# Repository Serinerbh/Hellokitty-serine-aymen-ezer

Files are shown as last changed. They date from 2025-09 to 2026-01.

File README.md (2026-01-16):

# 🐱 HelloKitty – Projet Robot Chat


### **Les contributeurs :**
-BENJEMAA Aymen
-SOLTANI Ezer
-ROUABAH Serine

## 📚 Table des matières

1. [📜 Présentation générale](#-présentation-générale)
2. [📐 Architecture matérielle](#-architecture-matérielle)
   - [🔌 Schéma système](#-schéma-système)
   - [📌 Pinout STM32](#-pinout-stm32)
   - [🛠️ PCB et design électronique](#-pcb-et-design-électronique)
3. [🧩 Architecture logicielle](#-architecture-logicielle)
   - [🧱 Couches logicielles](#-couches-logicielles)
   - [🕒 Fonctionnement des tâches FreeRTOS](#-fonctionnement-des-tâches-freertos)
   - [🔄 Synchronisation et priorités](#-synchronisation-et-priorités)
4. [⚙️ Drivers et HAL](#-drivers-et-hal)
5. [🎯 Stratégie comportementale](#-stratégie-comportementale)
6. [📊 Tests et validation](#-tests-et-validation)
7. [🔧 Résultats et perspectives](#-résultats-et-perspectives)

## Présentation générale

HelloKitty est un robot mobile autonome conçu pour évoluer sur une surface plane sans bordure, dans un jeu de poursuite entre plusieurs robots. Le projet s’inscrit dans le cadre du module Systèmes Électroniques Avancés de l’ENSEA, et vise à couvrir l’ensemble du cycle de développement embarqué : de la conception du PCB à l’implémentation logicielle temps réel, en passant par la stratégie comportementale.

Le robot est capable de détecter les bords, d’éviter les chutes, de repérer d’autres robots, et de changer de rôle (chat ↔ souris) en fonction des interactions physiques ou visuelles. Le projet met en œuvre des capteurs variés, une architecture logicielle modulaire, et une gestion fine des tâches concurrentes via FreeRTOS.

## **Architecture**  
### **Schéma architectural**  

schema_projet

#  Architecture du système embarqué STM32G431CBU6

Ce projet repose sur un microcontrôleur **STM32G431CBU6**, intégrant divers capteurs, modules de communication, moteurs et interfaces utilisateur pour créer un système autonome capable de capter, traiter et agir dans un environnement physique.

##  Microcontrôleur central
- **STM32G431CBU6** : cœur du système, gère les communications, le traitement des données et le contrôle des périphériques.

## Alimentation
- **Batterie NiMH 7.2V 1.3Ah** : source principale d’énergie.
- **Régulateurs de tension** :
  - **MP1475DJ-LF-P** : convertit la tension en **5V**.
  - **BU33SD5WG-TR** : convertit en **3.3V** pour les composants sensibles.

## Capteurs et modules
- **4 capteurs TOF (Time-of-Flight)** : connectés via **I2C**, pour mesurer les distances.
- **Accéléromètre ADXL343** : connecté en **I2C**, pour détecter les mouvements.
- **Module Bluetooth** : communication sans fil via **UART**.
- **Lidar YDLIDAR X2** : capteur de télémétrie, connecté en **UART**.

## Horloge et programmation
- **Quartz 16MHz** : fournit une horloge stable au microcontrôleur.
- **STLink SWD** : interface de programmation et débogage.
- **Hclk** : 170Mhz.

## Moteurs et contrôle
- **2 pilotes de moteur ZXBM5210** : reçoivent des signaux **PWM** pour contrôler les moteurs gauche et droit.
- **Moteurs avec encodeurs** : permettent un retour de position et de vitesse.

## 🖱️ Interface utilisateur
- **LED** : sortie **GPIO**, pour signalisation.
- **Bouton utilisateur** : entrée **GPIO**, pour interaction manuelle.
- **Bouton reset** : pour redémarrer le système.

## 🔌 Connexions colorées
- **Rouge** : lignes d’alimentation **5V**
- **Orange** : lignes **3.3V**
- **Violet** : **I2C**
- **Bleu** : **UART**
- **Vert** : **GPIO**
- **Noir** : **PWM**

---

Ce schéma illustre l’interconnexion des modules pour un système embarqué intelligent et réactif.

## Fonctionnement interne du robot

Le robot ne se contente pas d’exécuter des actions simples : son microcontrôleur coordonne en continu l’ensemble des capteurs, moteurs et modules pour produire un comportement cohérent et réactif. Cette section décrit la logique interne qui permet au système de fonctionner de manière autonome.

### Organisation logicielle
Le logiciel embarqué est structuré en plusieurs tâches indépendantes.  
Chaque tâche s’occupe d’un domaine précis : analyse des distances, lecture des chocs, gestion des moteurs ou encore surveillance de l’environnement.  
Cette organisation évite qu’une opération bloque les autres et garantit une réactivité constante.

### Système de décision
Le robot suit une hiérarchie de priorités pour réagir correctement aux événements :
- **Sécurité immédiate** : arrêt ou retrait en cas de danger (vide, obstacle trop proche, choc).
- **Évitement** : choix de la direction la plus dégagée grâce aux données du LiDAR.
- **Déplacement normal** : progression ou patrouille lorsque l’environnement est stable.

Cette logique empêche les comportements incohérents et permet des réactions rapides.

### Gestion dynamique des moteurs
Les moteurs sont ajustés en permanence selon la situation :
- correction de trajectoire,
- adaptation de la vitesse,
- compensation en cas de résistance ou de choc.

Le microcontrôleur calcule ces ajustements en temps réel, tandis que les drivers appliquent les consignes via PWM.

### Fusion des capteurs
Les informations issues des différents capteurs sont combinées pour obtenir une vision plus fiable de l’environnement :
- les ToF surveillent les bords,
- le LiDAR analyse l’espace autour du robot,
- l’accéléromètre détecte les impacts ou blocages.

Cette fusion permet d’anticiper les risques et d’adapter le comportement du robot de manière fluide.

### États internes
Le robot fonctionne comme une machine à états, chacun correspondant à un comportement précis :
- exploration,
- évitement,
- collision détectée,
- danger de chute,
- blocage,
- repos.

Chaque état définit les actions à effectuer et les conditions pour passer à un autre état.

### Indicateurs lumineux
Les LEDs servent de retour visuel pour comprendre l’état du robot :
- clignotement rapide : alerte,
- clignotement lent : attente,
- lumière fixe : fonctionnement normal.

Elles permettent de diagnostiquer rapidement le comportement du robot sans accéder au code.

### Synchronisation des communications
Les différents protocoles (UART, SPI, I2C) fonctionnent en parallèle.  
Pour éviter les conflits, les échanges sont cadencés et certaines lectures sont prioritaires.  
Les interruptions matérielles assurent la prise en charge immédiate des événements critiques.

---

Cette architecture logicielle permet au robot d’être autonome, réactif et capable de s’adapter en temps réel à son environnement.

##  Partie Hardware

Cette section décrit l’architecture matérielle du robot, ses composants électroniques, et les schémas associés.


### 🔌 Schéma global du système
Le système repose sur un microcontrôleur **STM32G431CBU6** qui coordonne les capteurs, les moteurs, les régulateurs et les interfaces utilisateur.

---

### ⚙️ Microcontrôleur et interfaces
Le microcontrôleur est au cœur du système. Il est connecté :
- aux moteurs via des signaux **PWM** et des entrées d’encodeurs,
- aux capteurs via **UART**, **I2C**, et **GPIO**,
- à un **STLink/SWD** pour la programmation et le débogage.



---

### 🔋 Alimentation et régulation
Le robot est alimenté par une batterie **NiMH 7.2V**, régulée en deux tensions :
- **5V** via le régulateur **MP1475DJ-LF-P**,
- **3.3V** via le régulateur **BU33SD5WG-TR**.

Ces tensions alimentent les moteurs, le microcontrôleur et les capteurs sensibles.



---

### 🦾 Pilotes de moteurs
Chaque moteur est contrôlé par un circuit **ZXBM5210-SP**, avec :
- deux entrées **PWM** pour la vitesse et la direction,
- deux sorties vers le moteur (Motor+ / Motor−),
- des entrées d’encodeurs pour le retour de position.

Chaque moteur dispose de son propre driver et de ses propres signaux.



---

### 📡 Capteurs
Le système intègre :
- **4 capteurs TOF** pour la détection de bordure,
- **1 accéléromètre ADXL343** pour les chocs et mouvements,
- **1 LiDAR YDLIDAR X2** pour la cartographie et l’évitement,
- **1 module Bluetooth** pour la communication sans fil.

Tous ces capteurs sont connectés au microcontrôleur via **I2C**, **SPI**, **UART** ou **GPIO**.


---

### 🖱️ Interface utilisateur
Le robot dispose :
- de **LEDs** pour indiquer son état (obstacle, marche, pause…),
- d’un **bouton utilisateur** pour les interactions manuelles,
- d’un **bouton reset** pour redémarrer le système.
##im

---

### 🧩 Organisation des fichiers KiCad
Les schémas sont répartis en plusieurs fichiers :
- `pucontrolleur.kicad.sch` : microcontrôleur et interfaces
- `moteur1.kicad.sch` / `moteur2.kicad.sch` : circuits moteurs
- `regulateurs.kicad.sch` : alimentation
- `capteurs.kicad.sch` : capteurs et communication

---

Cette architecture matérielle permet au robot d’être autonome, réactif et modulaire. Chaque composant est interconnecté pour assurer un fonctionnement fluide et sécurisé.

https://github.com/user-attachments/assets/3a07851f-27b0-4f3c-a773-fe1d66b704f5

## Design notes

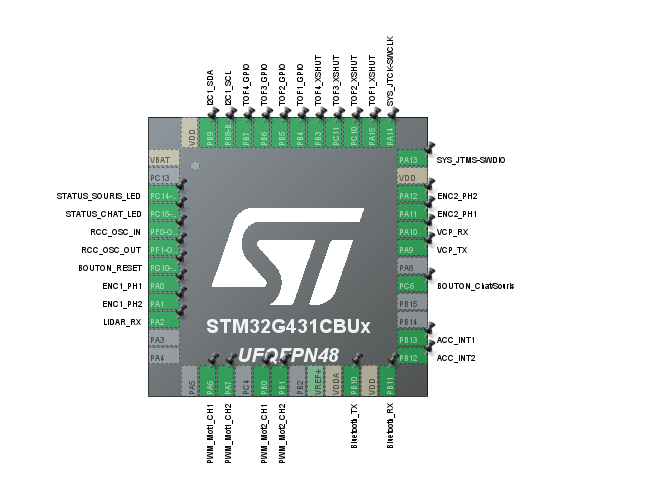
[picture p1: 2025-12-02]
Pinout.png

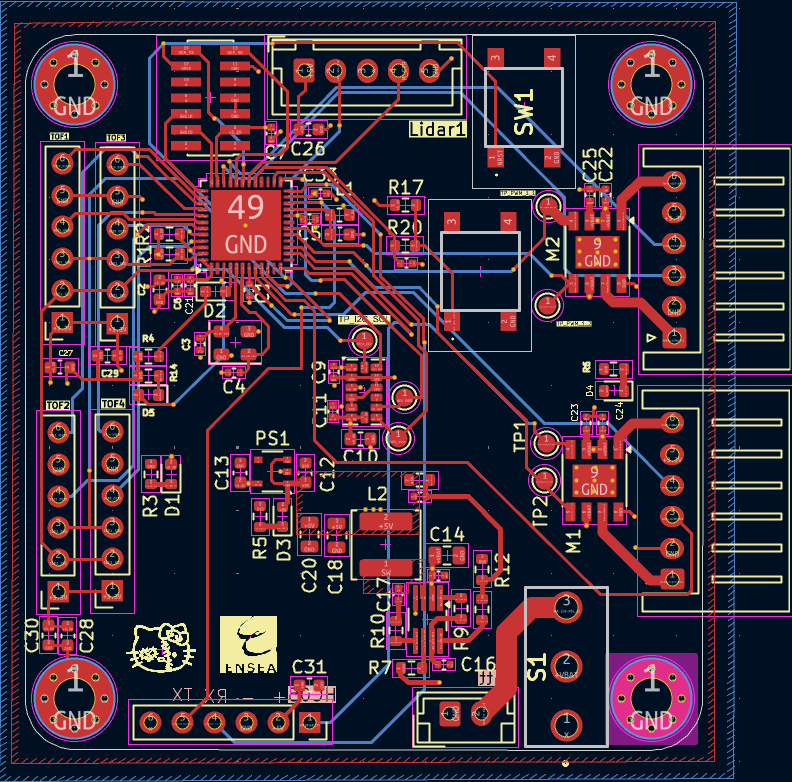
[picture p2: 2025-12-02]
schema.png

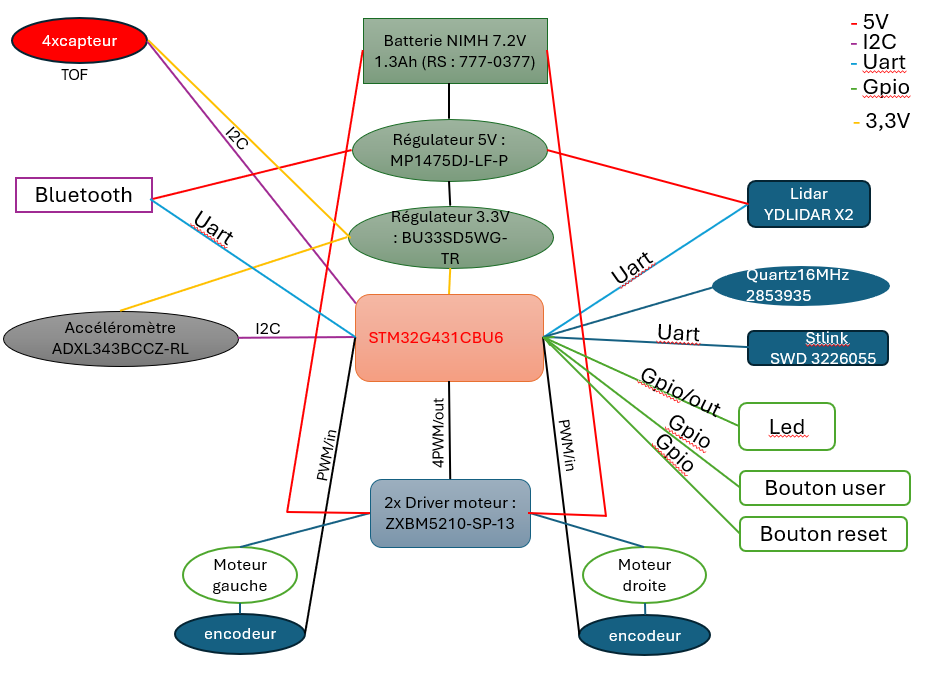
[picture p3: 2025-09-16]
schema_projet.png

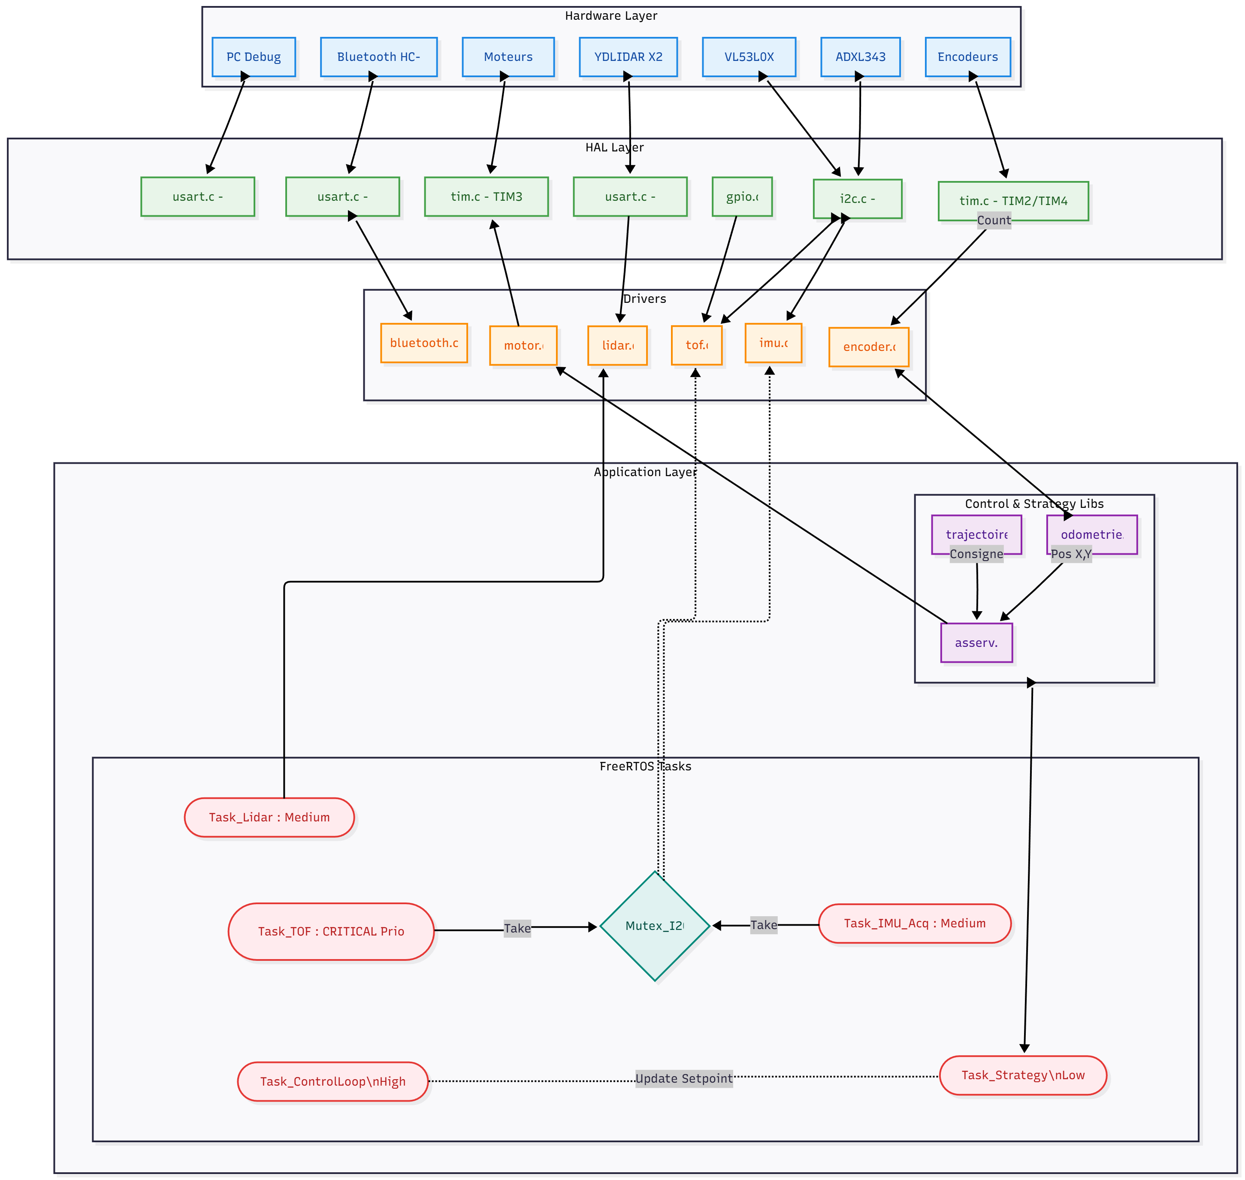
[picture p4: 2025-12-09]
diagram.png

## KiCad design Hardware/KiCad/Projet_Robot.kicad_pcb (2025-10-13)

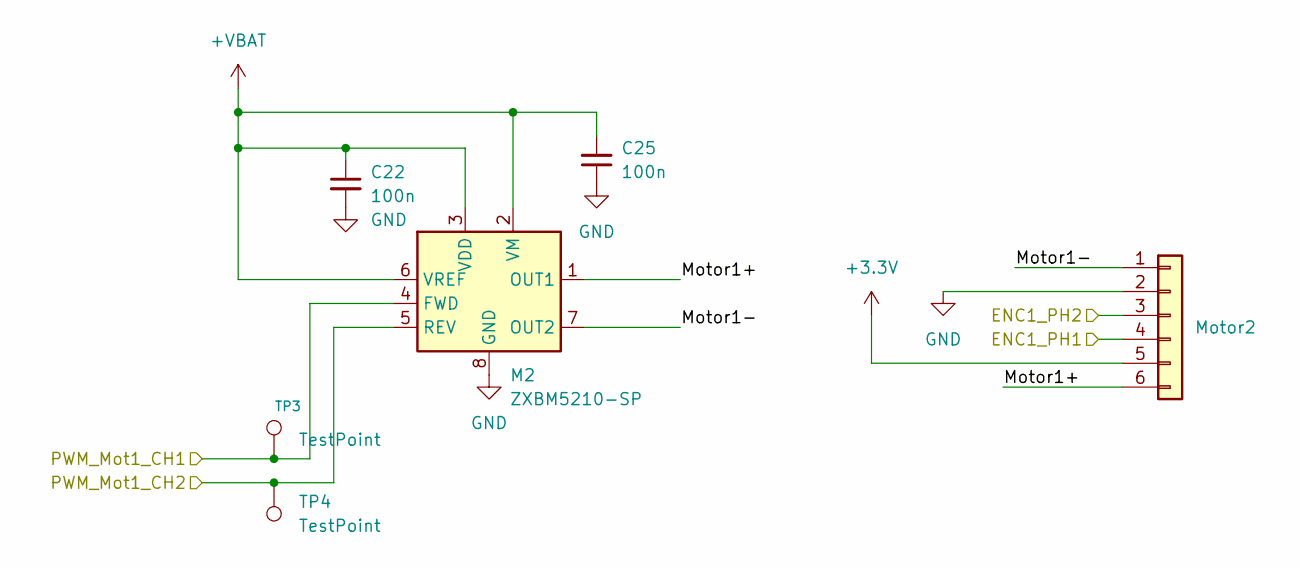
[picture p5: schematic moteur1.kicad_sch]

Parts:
C22, C25: 100n; C_0402_1005Metric
M2: ZXBM5210-SP; Diodes_SO-8EP
Motor2: Conn_01x06; JST_XH_S6B-XH-A_1x06_P2.50mm_Horizontal
TP3, TP4: TestPoint; TestPoint_Pad_D1.5mm

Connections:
+3.3V: Motor2.5; also elsewhere on the board
+VBAT: C22.1, C25.2, M2.2 (VM), M2.3 (VDD), M2.6 (VREF); also elsewhere on the board
/Moteur2/ENC1_PH1: Motor2.4; also elsewhere on the board
/Moteur2/ENC1_PH2: Motor2.3; also elsewhere on the board
/Moteur2/Motor1+: M2.1 (OUT1), Motor2.6
/Moteur2/Motor1-: M2.7 (OUT2), Motor2.1
/Moteur2/PWM_Mot1_CH1: M2.4 (FWD), TP3.1; also elsewhere on the board
GND: C22.2, C25.1, M2.8 (GND), M2.9 (GND), Motor2.2; also elsewhere on the board

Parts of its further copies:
C23, C24: 100n; C_0402_1005Metric
M1: ZXBM5210-SP; Diodes_SO-8EP
Motor1: Conn_01x06; JST_XH_S6B-XH-A_1x06_P2.50mm_Horizontal
TP1, TP2: TestPoint; TestPoint_Pad_D1.5mm

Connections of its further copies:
+3.3V: Motor1.5; also elsewhere on the board
+VBAT: C23.1, C24.2, M1.2 (VM), M1.3 (VDD), M1.6 (VREF); also elsewhere on the board
/Moteur1/ENC1_PH1: Motor1.4; also elsewhere on the board
/Moteur1/ENC1_PH2: Motor1.3; also elsewhere on the board
/Moteur1/Motor1+: M1.1 (OUT1), Motor1.6
/Moteur1/Motor1-: M1.7 (OUT2), Motor1.1
/Moteur1/PWM_Mot1_CH1: M1.4 (FWD), TP1.1; also elsewhere on the board
GND: C23.2, C24.1, M1.8 (GND), M1.9 (GND), Motor1.2; also elsewhere on the board

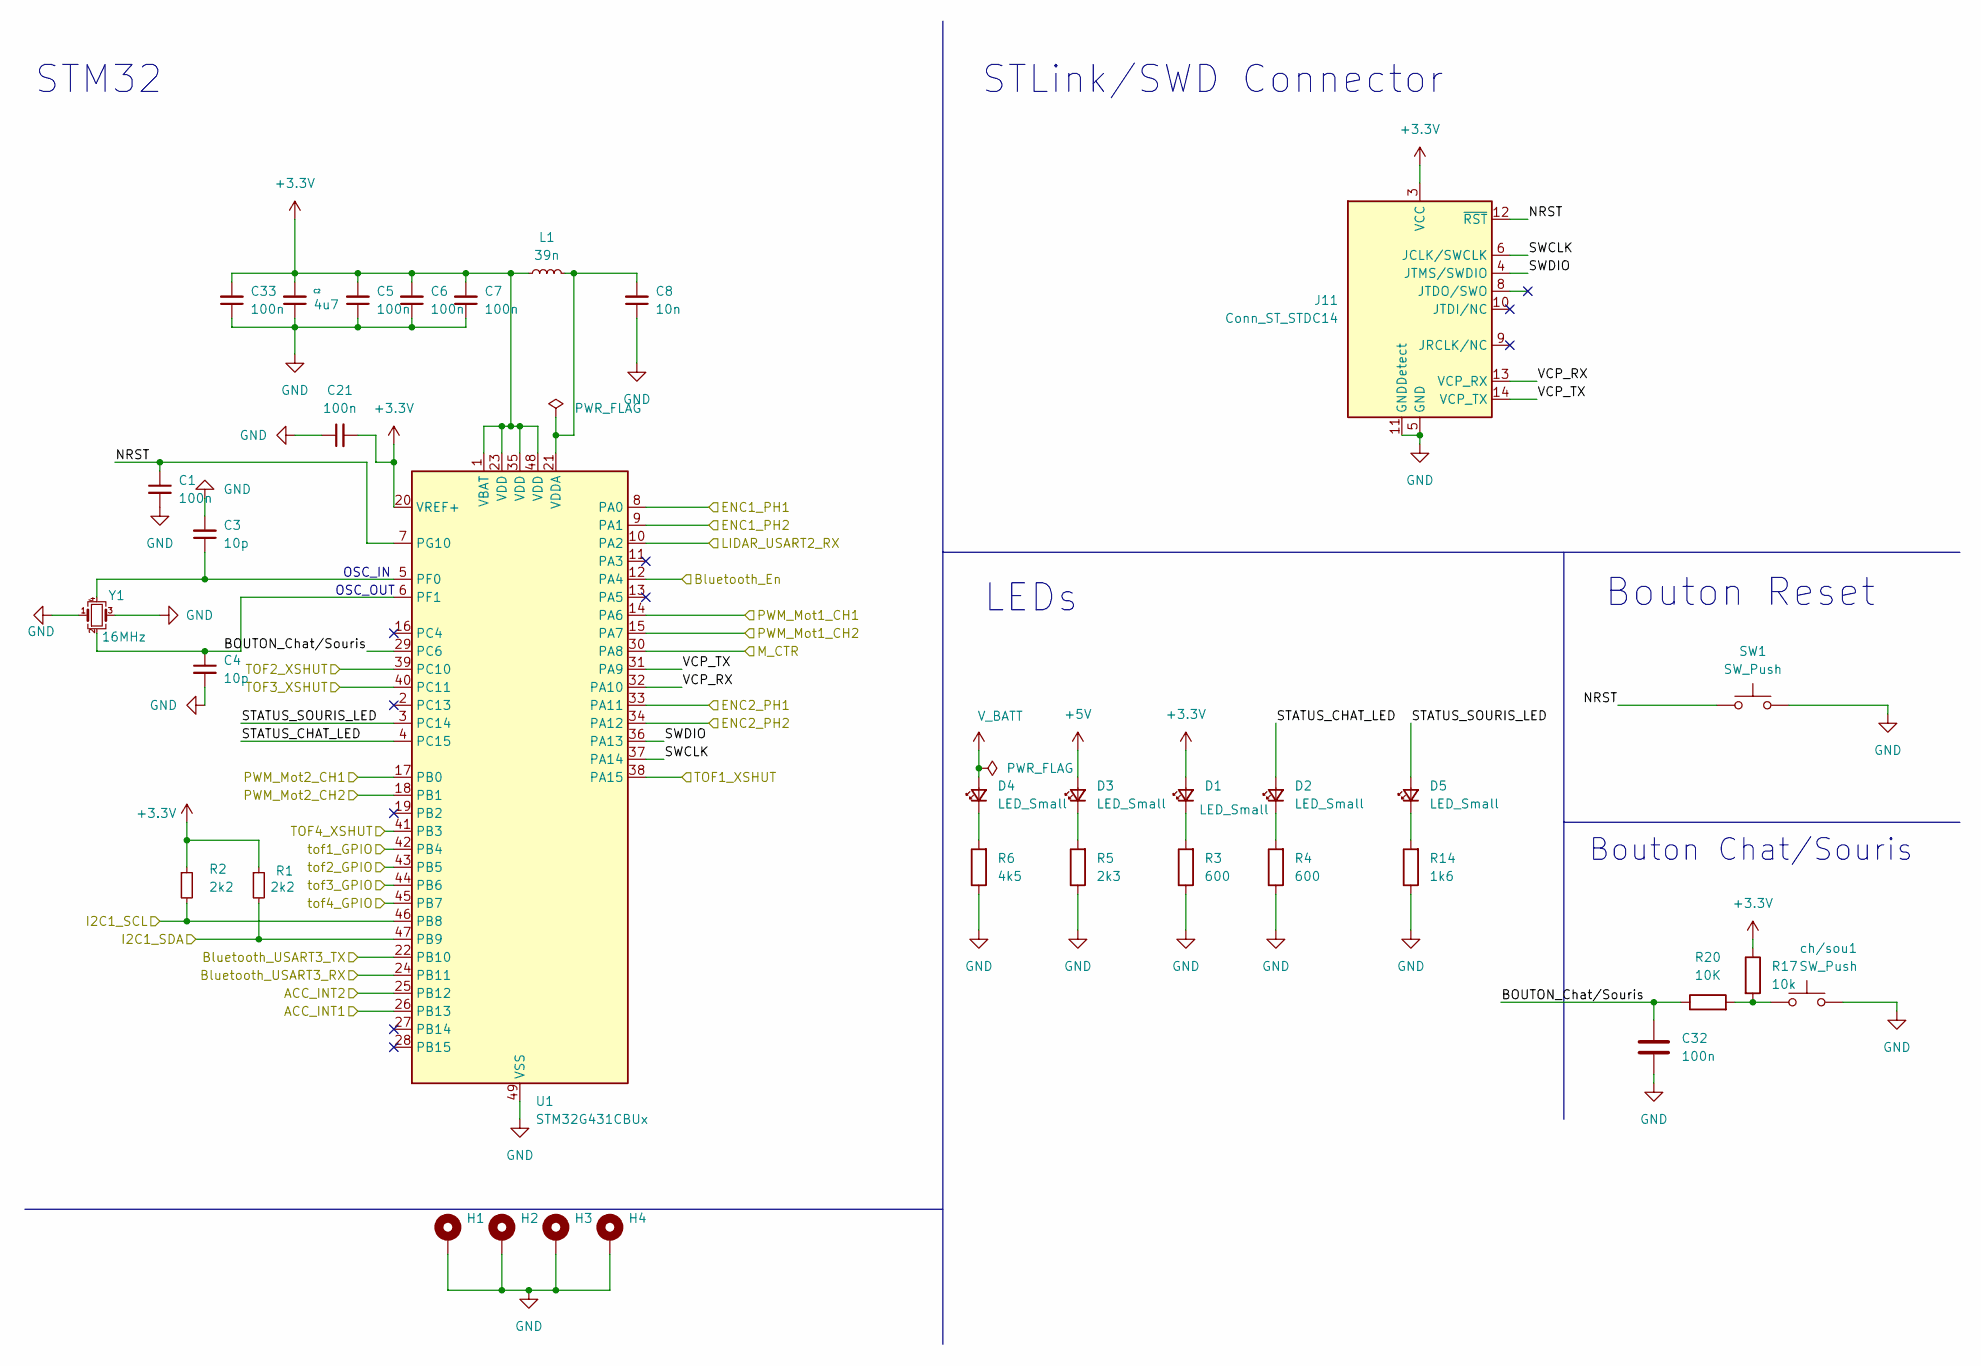
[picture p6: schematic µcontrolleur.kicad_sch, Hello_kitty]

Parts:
C1, C5, C6, C7, C21, C32, C33: 100n; C_0402_1005Metric
C2: 4u7; C_0603_1608Metric
C3, C4: 10p; C_0402_1005Metric
C8: 10n; C_0603_1608Metric
D1, D2, D3, D4, D5: LED_Small; LED_0603_1608Metric
H1, H2, H3, H4: MountingHole_Pad; MountingHole_3.2mm_M3_Pad_Via
J11: Conn_ST_STDC14; PinHeader_2x07_P1.27mm_Vertical_SMD
L1: 39n; L_0603_1608Metric
R1, R2: 2k2; R_0603_1608Metric
R3, R4: 600; R_0603_1608Metric
R5: 2k3; R_0603_1608Metric
R6: 4k5; R_0603_1608Metric
R14: 1k6; R_0603_1608Metric
R17: 10k; R_0603_1608Metric
R20: 10K; R_0603_1608Metric
SW1: SW_Push; SW Push 1P1T NO 6x6mm H9.5mm
U1: STM32G431CBUx; QFN-48-1EP_7x7mm_P0.5mm_EP5.6x5.6mm
Y1: 16MHz; Crystal_SMD_EuroQuartz_MT-4Pin_3.2x2.5mm
ch/sou1: SW_Push; SW Push 1P1T NO 6x6mm H9.5mm

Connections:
+3.3V: C2.2, C5.2, C6.2, C7.2, C21.2, C33.2, D1.2 (A), J11.3 (VCC), L1.1, R1.1, R2.1, R17.1, U1.1 (VBAT), U1.20 (VREF+), U1.23 (VDD), U1.35 (VDD), U1.48 (VDD); also elsewhere on the board
+5V: D3.2 (A); also elsewhere on the board
/Capteurs/ACC_INT1: U1.26 (PB13); also elsewhere on the board
/Capteurs/ACC_INT2: U1.25 (PB12); also elsewhere on the board
/Capteurs/Bluetooth_En: U1.12 (PA4); also elsewhere on the board
/Capteurs/Bluetooth_USART3_RX: U1.24 (PB11); also elsewhere on the board
/Capteurs/Bluetooth_USART3_TX: U1.22 (PB10); also elsewhere on the board
/Capteurs/I2C1_SCL: R2.2, U1.46 (PB8); also elsewhere on the board
/Capteurs/I2C1_SDA: R1.2, U1.47 (PB9); also elsewhere on the board
/Capteurs/LIDAR_USART2_RX: U1.10 (PA2); also elsewhere on the board
/Capteurs/M_CTR: U1.30 (PA8); also elsewhere on the board
/Capteurs/TOF1_XSHUT: U1.38 (PA15); also elsewhere on the board
/Capteurs/TOF2_XSHUT: U1.39 (PC10); also elsewhere on the board
/Capteurs/TOF3_XSHUT: U1.40 (PC11); also elsewhere on the board
/Capteurs/TOF4_XSHUT: U1.41 (PB3); also elsewhere on the board
/Capteurs/tof1_GPIO: U1.42 (PB4); also elsewhere on the board
/Capteurs/tof2_GPIO: U1.43 (PB5); also elsewhere on the board
/Capteurs/tof3_GPIO: U1.44 (PB6); also elsewhere on the board
/Capteurs/tof4_GPIO: U1.45 (PB7); also elsewhere on the board
/Moteur1/ENC1_PH1: U1.8 (PA0); also elsewhere on the board
/Moteur1/ENC1_PH2: U1.9 (PA1); also elsewhere on the board
/Moteur1/PWM_Mot1_CH1: U1.14 (PA6); also elsewhere on the board
/Moteur2/ENC1_PH1: U1.33 (PA11); also elsewhere on the board
/Moteur2/ENC1_PH2: U1.34 (PA12); also elsewhere on the board
/Moteur2/PWM_Mot1_CH1: U1.17 (PB0); also elsewhere on the board
/µcontrolleur/BOUTON_Chat/Souris: C32.1, R20.1, U1.29 (PC6)
/µcontrolleur/NRST: C1.1, J11.12 (~RST), SW1.1, U1.7 (PG10)
/µcontrolleur/STATUS_CHAT_LED: D2.2 (A), U1.4 (PC15)
/µcontrolleur/STATUS_SOURIS_LED: D5.2 (A), U1.3 (PC14)
/µcontrolleur/SWCLK: J11.6 (JCLK/SWCLK), U1.37 (PA14)
/µcontrolleur/SWDIO: J11.4 (JTMS/SWDIO), U1.36 (PA13)
/µcontrolleur/VCP_RX: J11.13 (VCP_RX), U1.32 (PA10)
/µcontrolleur/VCP_TX: J11.14 (VCP_TX), U1.31 (PA9)
GND: C1.2, C2.1, C3.2, C4.2, C5.1, C6.1, C7.1, C8.1, C21.1, C32.2, C33.1, H1.1, H2.1, H3.1, H4.1, J11.5 (GND), J11.7 (GND), J11.11 (GNDDetect), R3.1, R4.1, R5.1, R6.1, R14.1, SW1.2, U1.49 (VSS), Y1.1, Y1.3, ch/sou1.2; also elsewhere on the board
unnamed: D1.1 (K), R3.2
unnamed: D2.1 (K), R4.2
unnamed: D3.1 (K), R5.2
unnamed: D4.1 (K), R6.2
unnamed: D5.1 (K), R14.2
unnamed: R17.2, R20.2, ch/sou1.1
unnamed: C3.1, U1.5 (PF0), Y1.4
unnamed: C4.1, U1.6 (PF1), Y1.2
unnamed: C8.2, L1.2, U1.21 (VDDA)
V_BATT: D4.2 (A)

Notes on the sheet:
OSC_OUT
STM32
LEDs
STLink/SWD Connector
Bouton Chat/Souris
Bouton Reset
OSC_IN

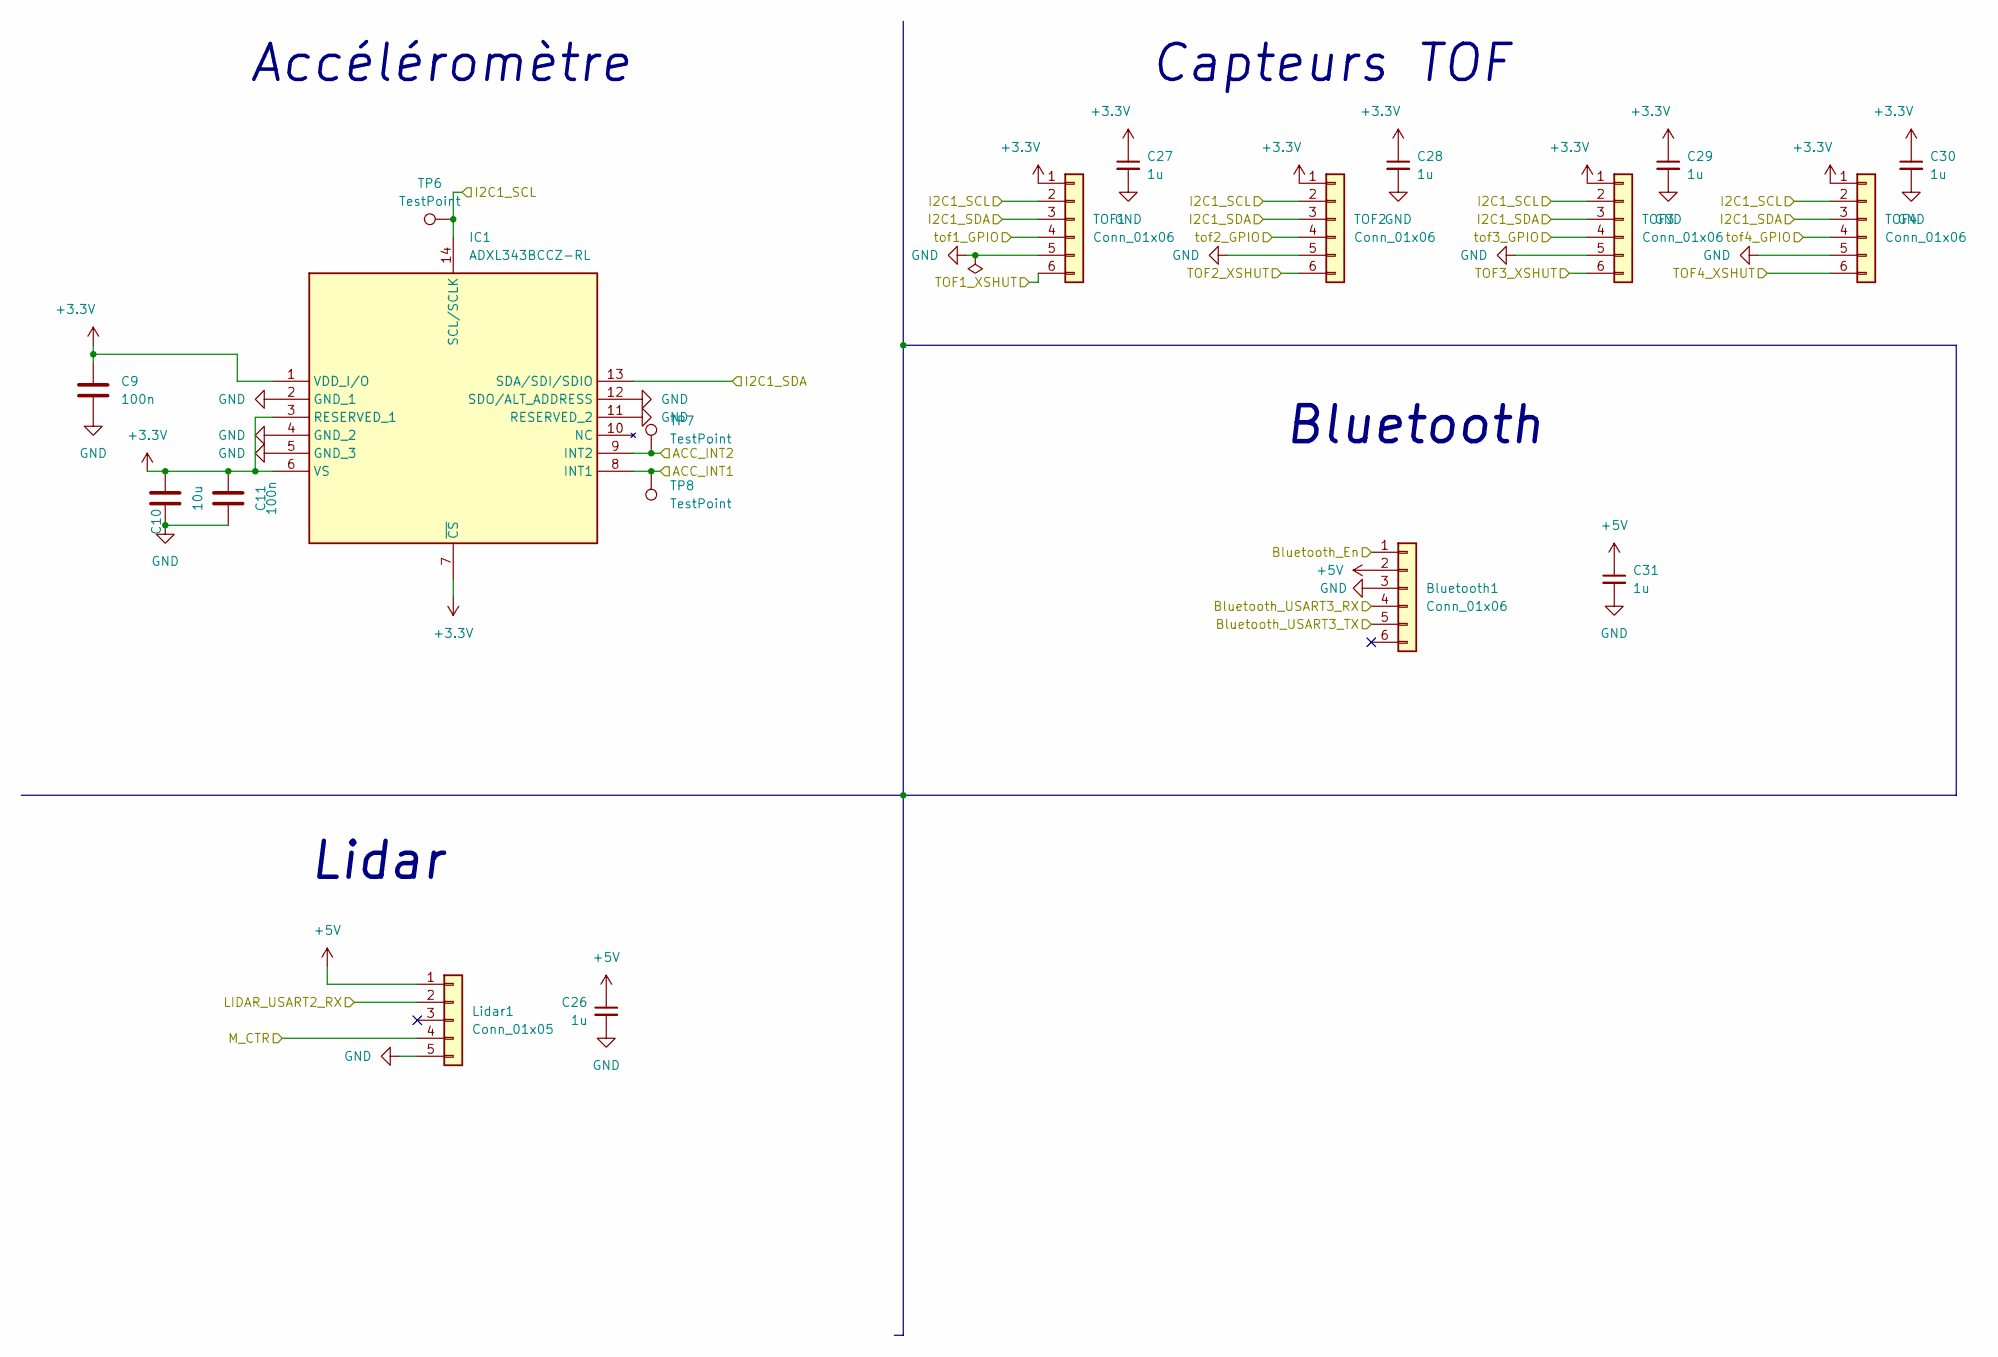
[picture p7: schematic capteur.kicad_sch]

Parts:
Bluetooth1: Conn_01x06; PinSocket_1x06_P2.54mm_Vertical
C9, C11: 100n; C_0402_1005Metric
C10: 10u; C_0603_1608Metric
C26, C27, C28, C29, C30, C31: 1u; C_0603_1608Metric
IC1: ADXL343BCCZ-RL; LGA-14_3x5mm_P0.8mm_LayoutBorder1x6y; Mouser Part Number 584-ADXL343BCCZ-R
Lidar1: Conn_01x05; JST_XH_B5B-XH-A_1x05_P2.50mm_Vertical
TOF1, TOF2, TOF3, TOF4: Conn_01x06; PinSocket_1x06_P2.54mm_Vertical
TP6, TP7, TP8: TestPoint; TestPoint_Pad_D1.5mm

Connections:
+3.3V: C9.2, C10.2, C11.2, C27.1, C28.1, C29.1, C30.1, IC1.1 (VDD_I/O), IC1.3 (RESERVED_1), IC1.6 (VS), IC1.7 (~CS), TOF1.1, TOF2.1, TOF3.1, TOF4.1; also elsewhere on the board
+5V: Bluetooth1.2, C26.1, C31.1, Lidar1.1; also elsewhere on the board
/Capteurs/ACC_INT1: IC1.8 (INT1), TP8.1; also elsewhere on the board
/Capteurs/ACC_INT2: IC1.9 (INT2), TP7.1; also elsewhere on the board
/Capteurs/Bluetooth_En: Bluetooth1.1; also elsewhere on the board
/Capteurs/Bluetooth_USART3_RX: Bluetooth1.4; also elsewhere on the board
/Capteurs/Bluetooth_USART3_TX: Bluetooth1.5; also elsewhere on the board
/Capteurs/I2C1_SCL: IC1.14 (SCL/SCLK), TOF1.2, TOF2.2, TOF3.2, TOF4.2, TP6.1; also elsewhere on the board
/Capteurs/I2C1_SDA: IC1.13 (SDA/SDI/SDIO), TOF1.3, TOF2.3, TOF3.3, TOF4.3; also elsewhere on the board
/Capteurs/LIDAR_USART2_RX: Lidar1.2; also elsewhere on the board
/Capteurs/M_CTR: Lidar1.4; also elsewhere on the board
/Capteurs/TOF1_XSHUT: TOF1.6; also elsewhere on the board
/Capteurs/TOF2_XSHUT: TOF2.6; also elsewhere on the board
/Capteurs/TOF3_XSHUT: TOF3.6; also elsewhere on the board
/Capteurs/TOF4_XSHUT: TOF4.6; also elsewhere on the board
/Capteurs/tof1_GPIO: TOF1.4; also elsewhere on the board
/Capteurs/tof2_GPIO: TOF2.4; also elsewhere on the board
/Capteurs/tof3_GPIO: TOF3.4; also elsewhere on the board
/Capteurs/tof4_GPIO: TOF4.4; also elsewhere on the board
GND: Bluetooth1.3, C9.1, C10.1, C11.1, C26.2, C27.2, C28.2, C29.2, C30.2, C31.2, IC1.2 (GND_1), IC1.4 (GND_2), IC1.5 (GND_3), IC1.11 (RESERVED_2), IC1.12 (SDO/ALT_ADDRESS), Lidar1.5, TOF1.5, TOF2.5, TOF3.5, TOF4.5; also elsewhere on the board

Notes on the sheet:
Lidar
Bluetooth
Accéléromètre
Capteurs TOF

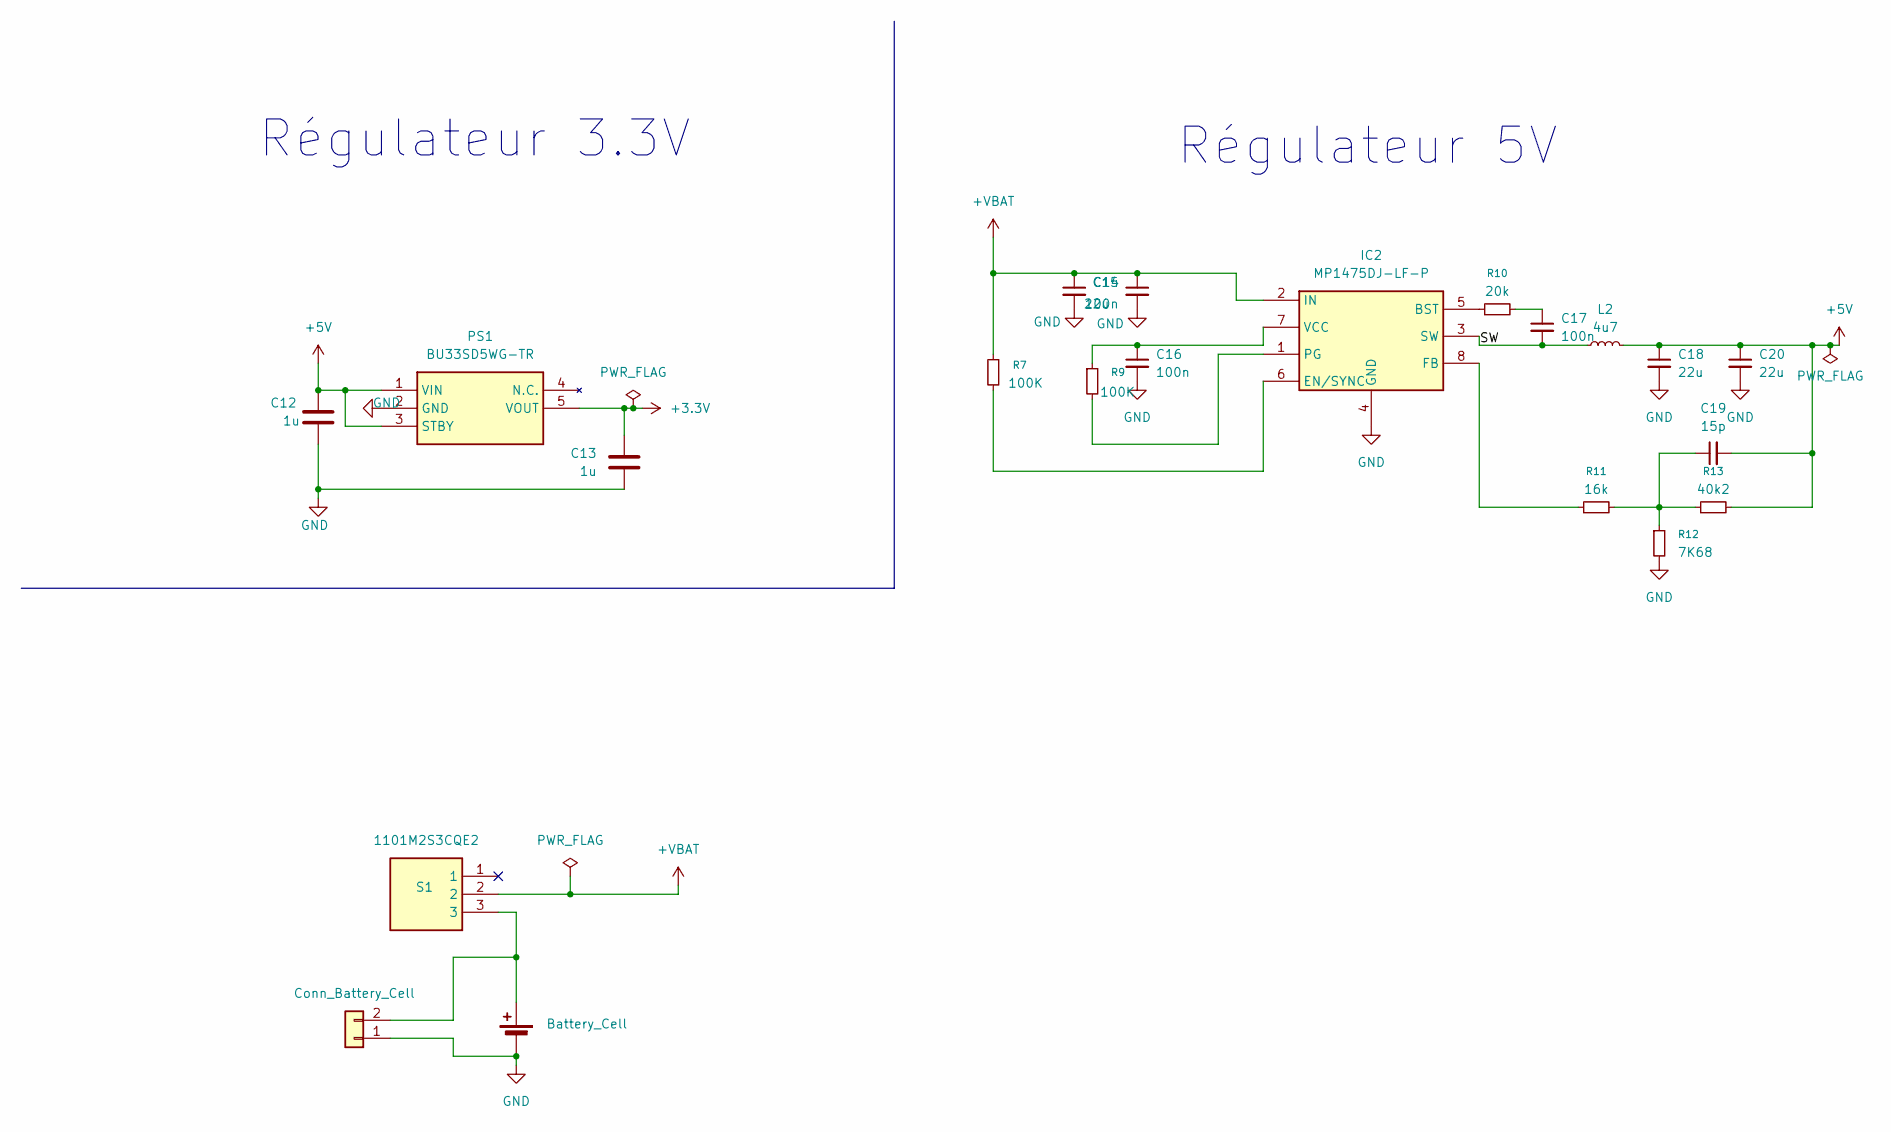
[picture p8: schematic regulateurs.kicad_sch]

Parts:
BT1: Battery_Cell; JST_XH_S2B-XH-A-1_1x02_P2.50mm_Horizontal
C12, C13: 1u; C_0603_1608Metric
C14, C18, C20: 22u; C_0805_2012Metric
C15, C16, C17: 100n; C_0402_1005Metric
C19: 15p; C_0402_1005Metric
IC2: MP1475DJ-LF-P; TSOT-23-8_HandSoldering; Manufacturer_Part_Number MP1475DJ-LF-P
J1: Conn_Battery_Cell; JST_EH_B2B-EH-A_1x02_P2.50mm_Vertical
L2: 4u7; L_APV_ANR5040
PS1: BU33SD5WG-TR; TSOP-5_1.65x3.05mm_P0.95mm; Manufacturer_Part_Number BU33SD5WG-TR; Mouser Part Number 755-BU33SD5WG-TR
R7, R9: 100K; R_0603_1608Metric
R10: 20k; R_0603_1608Metric
R11: 16k; R_0603_1608Metric
R12: 7K68; R_0603_1608Metric
R13: 40k2; R_0603_1608Metric
S1: 1101M2S3CQE2; 1101M2S3QE2; Manufacturer_Part_Number 1101M2S3CQE2

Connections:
+3.3V: C13.2, PS1.5 (VOUT); also elsewhere on the board
+5V: C12.1, C18.1, C19.2, C20.1, L2.2, PS1.1 (VIN), PS1.3 (STBY), R13.2; also elsewhere on the board
+VBAT: C14.1, C15.1, IC2.2 (IN), R7.1, S1.2; also elsewhere on the board
/Régulateurs/SW: C17.2, IC2.3 (SW), L2.1
GND: C12.2, C13.1, C14.2, C15.2, C16.2, C18.2, C20.2, IC2.4 (GND), J1.1, PS1.2 (GND), R12.2; also elsewhere on the board
unnamed: C17.1, R10.2
unnamed: C19.1, R11.2, R12.1, R13.1
unnamed: IC2.5 (BST), R10.1
unnamed: IC2.6 (EN/SYNC), R7.2
unnamed: IC2.8 (FB), R11.1
unnamed: IC2.1 (PG), R9.2
unnamed: C16.1, IC2.7 (VCC), R9.1
unnamed: BT1.1 (+), J1.2, S1.3

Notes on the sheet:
Régulateur 5V
Régulateur 3.3V

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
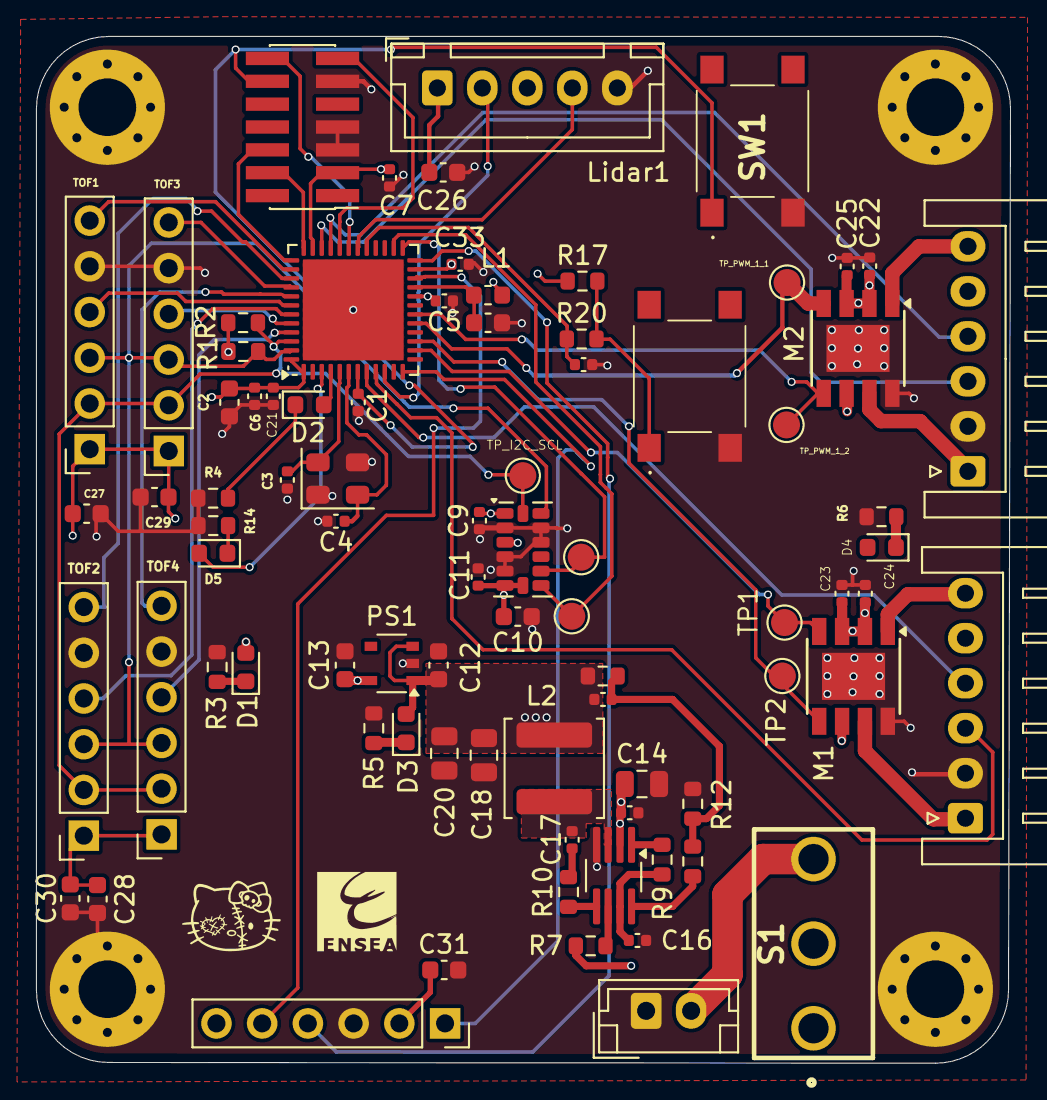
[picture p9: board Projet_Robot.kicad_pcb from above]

Board: 4 copper layers, 54.1 x 57.0 mm, 87 parts (0 on the bottom side), 59 nets.

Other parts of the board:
HelloKitty: L; logo hello
TP_PWM_1_2: TestPoint; TestPoint_Pad_D1.5mm

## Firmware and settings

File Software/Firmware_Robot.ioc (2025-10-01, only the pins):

Mcu.UserName=STM32G431CBUx
PA0.GPIO_Label=ENC1_PH1
PA0.Signal=S_TIM2_CH1
PA1.GPIO_Label=ENC1_PH2
PA1.Signal=S_TIM2_CH2
PA10.GPIO_Label=VCP_RX
PA10.Signal=USART1_RX
PA11.GPIO_Label=ENC2_PH1
PA11.Signal=S_TIM4_CH1
PA12.GPIO_Label=ENC2_PH2
PA12.Signal=S_TIM4_CH2
PA13.Signal=SYS_JTMS-SWDIO
PA14.Signal=SYS_JTCK-SWCLK
PA15.GPIO_Label=TOF1_XSHUT
PA15.Signal=GPIO_Output
PA2.GPIO_Label=LIDAR_RX
PA2.Signal=USART2_TX
PA6.GPIO_Label=PWM_Mot1_CH1
PA6.Signal=S_TIM3_CH1
PA7.GPIO_Label=PWM_Mot1_CH2
PA7.Signal=S_TIM3_CH2
PA9.GPIO_Label=VCP_TX
PA9.Signal=USART1_TX
PB0.GPIO_Label=PWM_Mot2_CH1
PB0.Signal=S_TIM3_CH3
PB1.GPIO_Label=PWM_Mot2_CH2
PB1.Signal=S_TIM3_CH4
PB10.GPIO_Label=Bluetooth_TX
PB10.Signal=USART3_TX
PB11.GPIO_Label=Bluetooth_RX
PB11.Signal=USART3_RX
PB12.GPIO_Label=ACC_INT2
PB12.Signal=GPIO_Input
PB13.GPIO_Label=ACC_INT1
PB13.Signal=GPIO_Input
PB3.GPIO_Label=TOF4_XSHUT
PB3.Signal=GPIO_Output
PB4.GPIO_Label=TOF1_GPIO
PB4.Signal=GPIO_Output
PB5.GPIO_Label=TOF2_GPIO
PB5.Signal=GPIO_Output
PB6.GPIO_Label=TOF3_GPIO
PB6.Signal=GPIO_Output
PB7.GPIO_Label=TOF4_GPIO
PB7.Signal=GPIO_Output
PB8-BOOT0.Signal=I2C1_SCL
PB9.Signal=I2C1_SDA
PC10.GPIO_Label=TOF2_XSHUT
PC10.Signal=GPIO_Output
PC11.GPIO_Label=TOF3_XSHUT
PC11.Signal=GPIO_Output
PC14-OSC32_IN.GPIO_Label=STATUS_SOURIS_LED
PC14-OSC32_IN.Signal=GPIO_Output
PC15-OSC32_OUT.GPIO_Label=STATUS_CHAT_LED
PC15-OSC32_OUT.Signal=GPIO_Output
PC6.GPIO_Label=BOUTON_Chat/Souris
PC6.Signal=GPIO_Input
PF0-OSC_IN.Signal=RCC_OSC_IN
PF1-OSC_OUT.Signal=RCC_OSC_OUT
PG10-NRST.GPIO_Label=BOUTON_RESET
PG10-NRST.Signal=GPIO_Input

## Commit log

2025-09-24 review pcb
    [Projet_Robot.kicad_pcb, Projet_Robot.kicad_sch, capteur.kicad_sch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]
2025-09-24 1
    u
    [moteur1.kicad_sch]
2025-09-30 s
    s
    [Projet_Robot.kicad_pcb, capteur.kicad_sch, regulateurs.kicad_sch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]
2025-10-13 check LF
    [Projet_Robot.kicad_pcb, capteur.kicad_sch, moteur1.kicad_sch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]
2025-11-18 test motor
2025-12-02 Ajout des tests unitaires : accéléromètre et LIDAR
2025-12-03 code Drivers HC_05
2025-12-09 Driver Lidar & Accelerometre
2025-12-09 Update driver Lidar & IMU
2025-12-10 intégration des tâches FreeRTOS : Lidar & Accélerometre
2025-12-13 Intégration FreeRTOS avec drivers Lidar, IMU, TOF et moteurs
2026-01-01 asservissement PID, sécurité TOF par interruption et filtrage LIDAR
2026-01-09 Implémentation architecture FreeRTOS (Control, Safety, Lidar, IMU)
2026-01-09 implémentation de la stratégie, du suivi de cible et du contrôle Bluetooth
    - Ajout de la machine à états (RECHERCHE, ATTAQUE, FUITE) dans strategy.c.
    - Implémentation du changement de rôle dynamique (Chat/Souris) par détection de chocs (IMU).
    - Ajout du suivi de cible LIDAR avec lissage temporel (filtre Alpha).
    - Mise en place du contrôle Bluetooth (HC-05) : commandes START, STOP, CHAT, SOURIS.
    - Redirection des logs de debug (printf) vers l'UART Bluetooth (9600 bauds).
    - Intégration complète sous FreeRTOS avec des cycles d'exécution de 10Hz à 100Hz.
2026-01-09 implémentation complète de la stratégie de combat et finalisation du firmware
2026-01-14 Revise README for HelloKitty robot project
    Updated project title and added detailed table of contents with sections on hardware and software architecture, drivers, and testing.
2026-01-14 passage des TOF en polling et optimisation de l'anti-chute
2026-01-16 UPDATE lidar + strategy
